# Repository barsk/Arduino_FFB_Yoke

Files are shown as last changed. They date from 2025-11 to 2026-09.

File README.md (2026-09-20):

# SimInvent FFB Yoke 
A Force Feedback Yoke based on 775 DC motors and an Arduino (SparkFun) Micro Pro microcontroller. 

This is a fork of [Gagagu Arduino FFB Yoke](https://github.com/gagagu/Arduino_FFB_Yoke). The goals of this fork was to lower total cost, add new features, achieve a smaller footprint, use cheaper and use more accurate AS5600 magnetic encoders and maximize pitch travel distance.

# Documentation
***All build guides and documentation for the 3D printed parts, electronics and software are in the [Wiki section!](https://github.com/barsk/Arduino_FFB_Yoke/wiki/Home)***

# Support
The [SimInvent Discord Server](https://discord.gg/cZUywYGyt6) is the main support and chat channel for this project. You are welcome to chime in and join the community there!<br>
**Bug reports**, please create an [Issue](https://github.com/barsk/Arduino_FFB_Yoke/issues) so we can track bugs and issues. 

---

> # Version 1.0 Release
> First public feature complete release with a **host of new features and performance**
>
> ## Firmware
> The firmware is now **highly optimized** compared to the previous version.
> It is now **100% compliant** with the standard Microsoft USB PID 1.0 specification with the following notable changes and bug fixes:
> * Force loop rate runs about  **2.5 times as fast** due to optimizations in every part of the firmware - 
> * Sine lookup table with interpolation replaces the computationally expensive sin() function in the force loop  - Contributing 45% of the speedup in the force loop
> * Effect direction now follows the DirectInput specification fully - Force directions was previously **inversed** in some situations
>* Multi-second FFB command lag removed when several effects were playing simultaneously with high framerate - 
> Due to inefficient USB protocol reads the input queue could build up and cause multi second lag
> * Effects no longer cancel or distort each other under load - The force calculator routine summed up effect forces 
> incorrectly causing an internal integer overflow
> * Coasting at idle - The motor output stage was driven even when idle, so the yoke was efffectively braked when zero force was applied. This has now been fixed, at 0 force, the output stage disbles leaving the yoke unpowered.
> * Handling non-linear motor response - The 775 motor driven straight from a PWM from 0-255 will yield a non-linear response. First at PWM=~25-40 the axis will start to move at all. Not handled this will create a huge deadband. We have previously handled this in the Setting tool with a "Motor Start Power" to define a starting point from which the effects should start, that settles the starting point, but the response *over* that setting will be non-linear with an initial bump unrealistically amplifying small effect forces. There are now settings in the firmware to configure the handling of this. See [Handling non-linear motor response](https://github.com/barsk/Arduino_FFB_Yoke/wiki/Firmware#handling-non-linear-motor-response) in the Wiki Firmware section.
>
> ## New pitch axis design
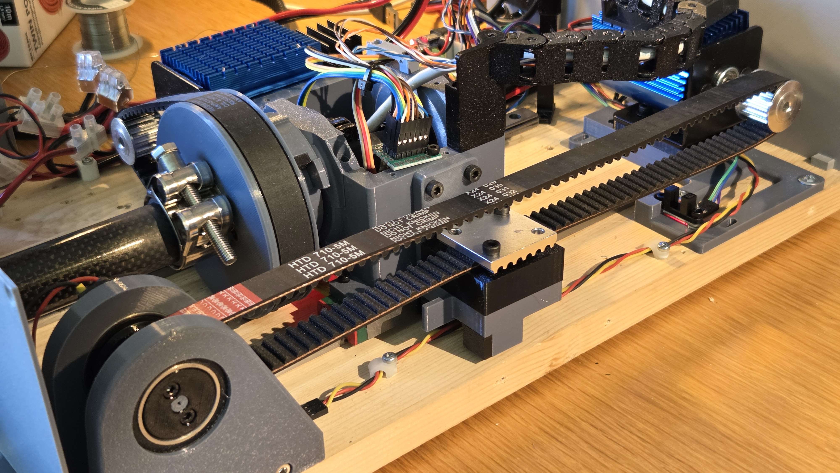
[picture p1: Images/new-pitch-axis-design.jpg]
new pitch design
> 
> The pitch axis previously featured a planetary gear on the motor. That gave the axis plenty of torque, but also introduced backlash 
> and friction. The backlash creates a lot of rattle on vibration effects and the friction makes the axis a bit numb on smaller forces.
> The new design removes the planetary gear and instead uses a 14T pulley with a 720 mm belt. This trades some of torque, but the pitch axis is still about 70% stronger than roll anyway. 
> The upside is that **pitch now feels nimble and direct**, you are more connected to the sim and aircraft and can feel it in you hands.  
> 
> If you built the former 30T + gears based version you need to get a new metal motor bracket (same as on roll), a 14t pulley and a 720 mm belt. You will also need to print a new idler pulley (also 14T), print a new frame belt clamp piece for the new raised belt position, and a new pitch motor mount for the new height.
>
> The previous design with planetary gears can still be used, see Wiki for details.
> ## FFBTestTool
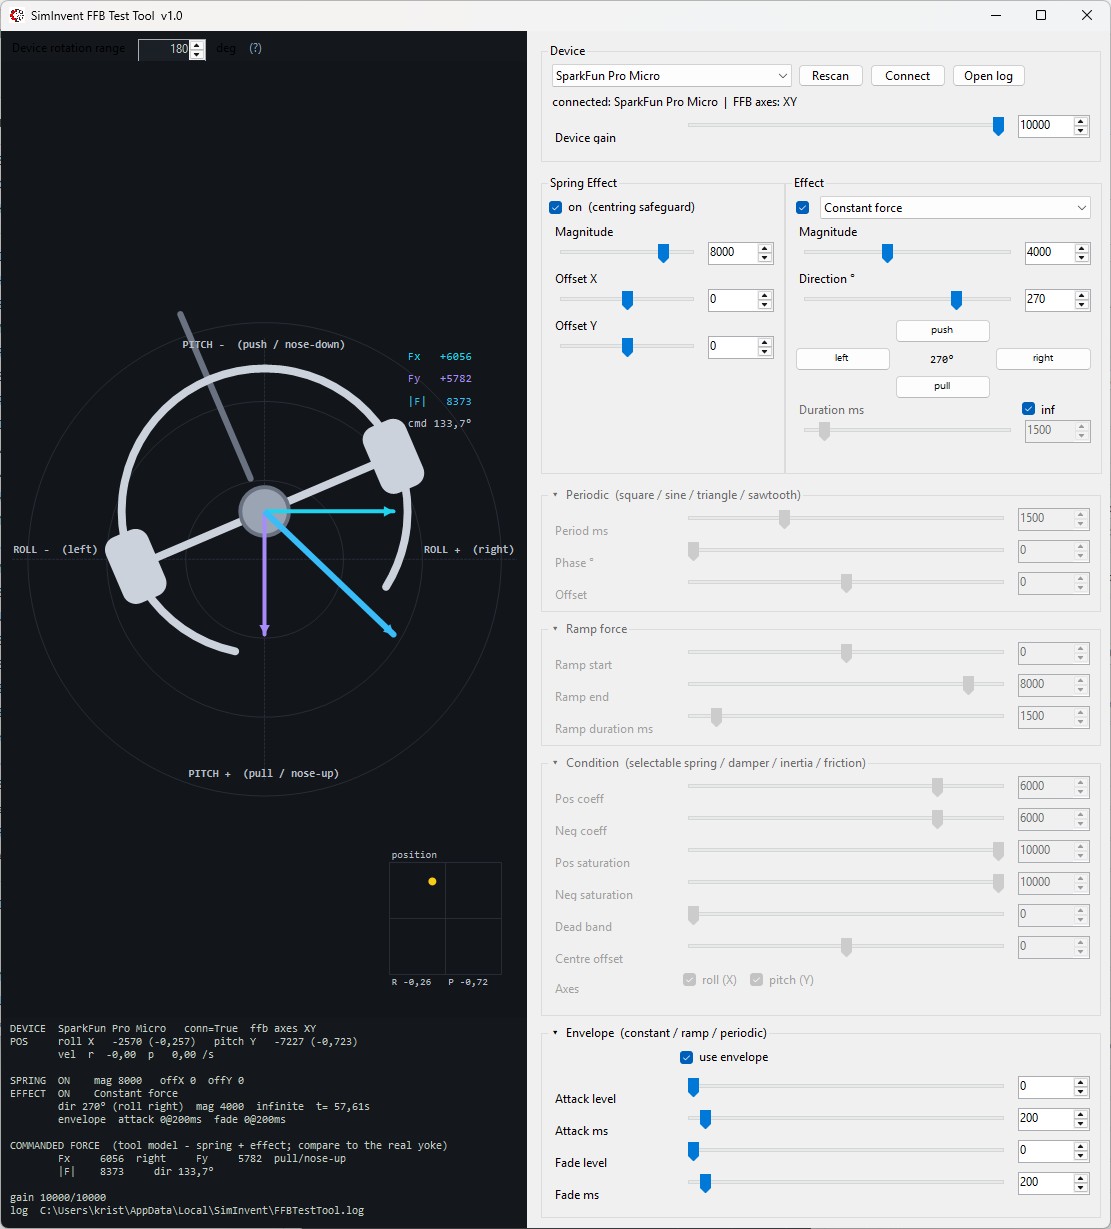
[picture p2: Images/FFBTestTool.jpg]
FFBTestTool

>There is now a new bundled **FFBTestTool.exe**, replacing the old ForceTest.exe that show you exactly what the 
> firmware sees from your built yoke, helping diagnosing magnetic encoders, travel, reversed motor wiring and 
> other faults, and confirming that every FFB effect is running and performing as expected with a graphical 
> view of the yoke and the forces applied to it.\
> Full details in https://github.com/barsk/FFBTestTool
> 
> ## Electronics
> The new PCBs (circuit boards) are now **fully tested!** Many thanks to **@PeteDDD** for his valuable contribution. All details are in the Wiki, Parts List and in the Electronics folder.

# Design and features compared to Gagagu Yoke
 
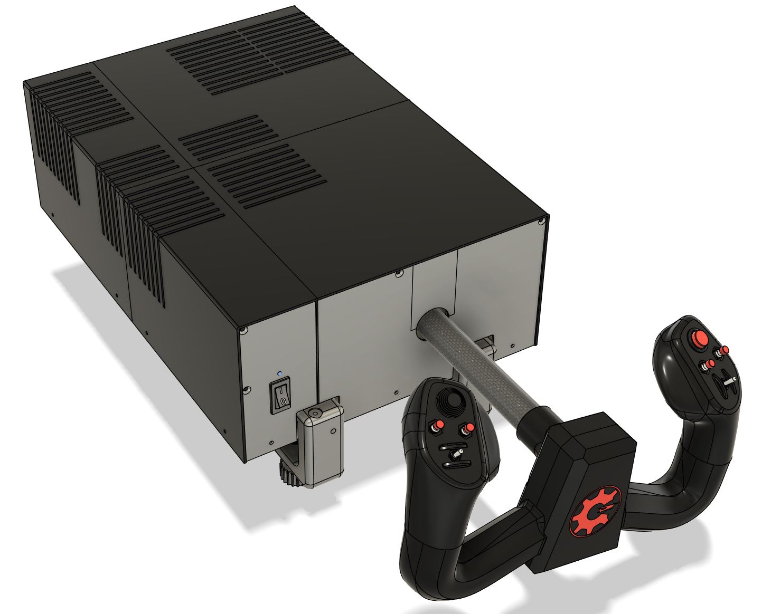
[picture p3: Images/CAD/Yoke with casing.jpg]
Yoke with casing
  
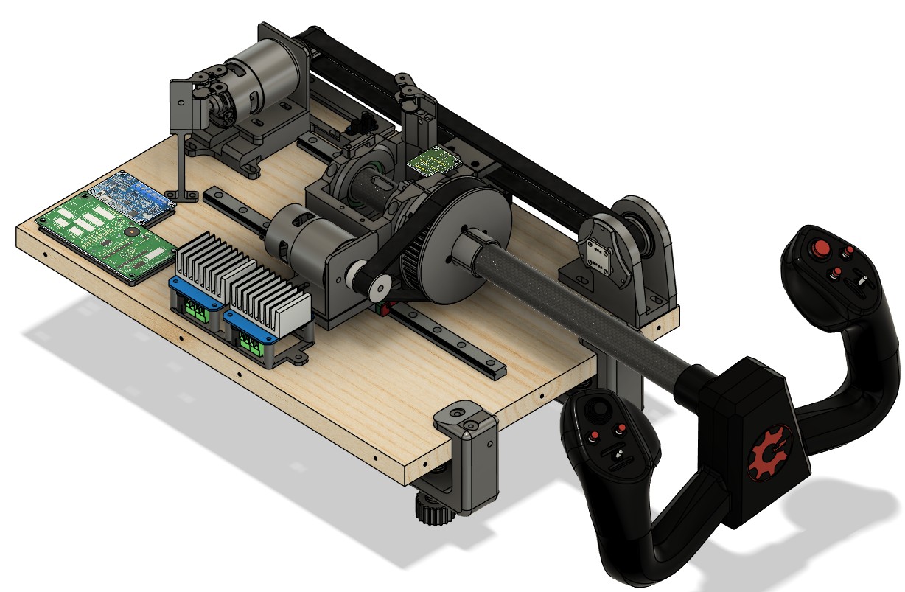
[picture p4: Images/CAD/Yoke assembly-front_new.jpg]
Yoke front

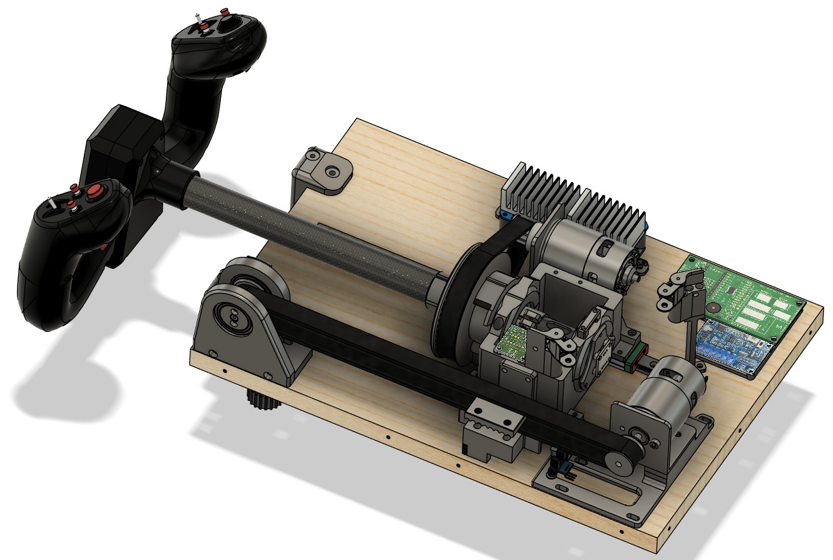
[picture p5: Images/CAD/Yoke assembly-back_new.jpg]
Yoke backside


* Completely new CAD design with focus on easy printing and assembly.
* New PCB design.
* Magnetic AS5600 encoders featuring 12 bit accuracy, saving cost, space and weight.
* Removed planetary gears in both roll and pitch axis which introduces backlash (slop), friction and considerable weight increasing mass and inertia. Roll axis with a 56T pulley, 12T motor drive. That gives a 4.7 gear ratio which is quite enough for roll forces and provides a more nimble, lively feel than the old design. Pitch axis now uses a 14T pulley. 
* Reduced footprint (400 x 275 x 100 mm).
* Pitch travel up to 165 mm with 720 mm belt on pitch (Y) axis. 
* Configurable pitch travel range in the settings tool.
* Default centering Spring force when non-FFB games are played.
* Yoke controller is remixed so that only 3 mm brass thread inserts is used. The mount bracket is updated for strength.
* Calibration method is completely revamped. It runs automatically on first start to find the endstops (IR sensors) at the extremes of the axis travel. It can also be manually started by a button at any time. 
* The calibration data is stored in EEPROM and recalled on subsequent reboot. 
* Cable chain link. To prevent breakage of the cabling a chain link is used in the design. This will give all cables from the yoke handle and frame sensors a controlled bend characteristic with a big radius preventing acute bending and breakage. 
* A 3D printed casing with plenty of cooling slots for ventilation is part of the design and fully integrated. The casing is split up into four parts plus the front and back panels which is split in two each, providing a fully printable design despite its large size. The parts are assembled with (printed) dowels and glued or screwed together.

### Electronics and PCB (circuit boards)
**@PeteDDD** has graciously contributed new custom PCB designs. 
Gagagu version PCBs can still be used, with some modifications (see Wiki).
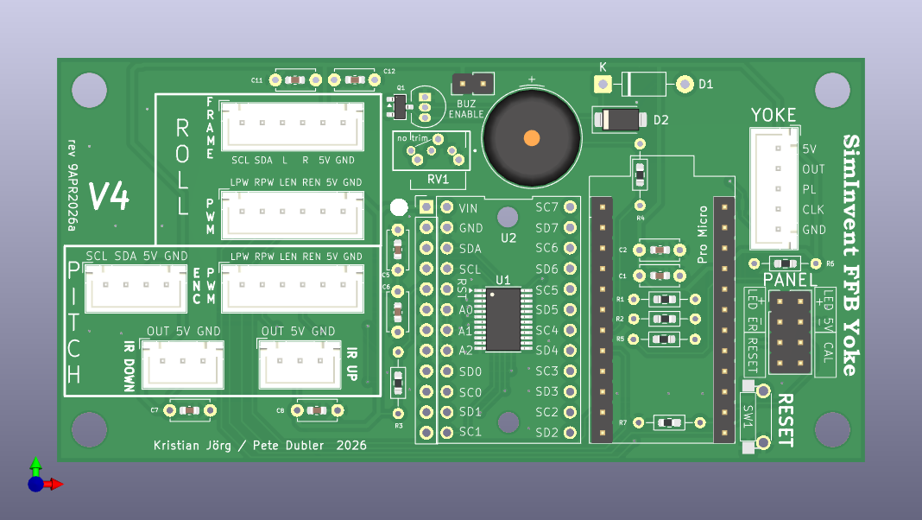
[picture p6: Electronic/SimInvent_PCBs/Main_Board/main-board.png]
New PCB


### Settings tool
A settings tool written in Python and Qt6. The tool features a sleek experience and features a robust and fast serial protocol.

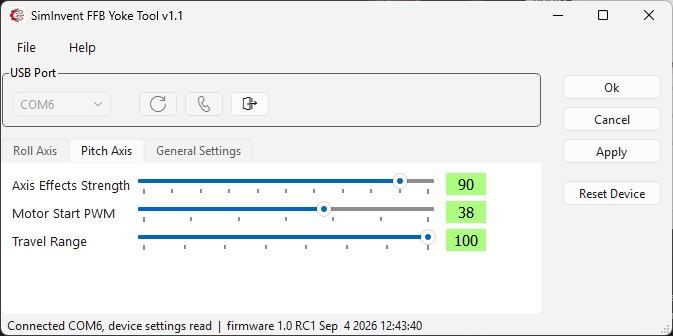
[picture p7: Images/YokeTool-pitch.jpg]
Settings tool


### 3D printed parts
No 3D printed parts are the same from the Gagagu/jwryan4 project. Every part has been redesigned from the ground up with focus on easy printing, strength, functionality and minimal footprint. The IR-based end-stop sensors are now integrated into the actual design in a way that need no careful positioning as before.

### Firmware
The firmware code is *heavily modified and enhanced* with new features and updated for the new AS5600 encoders and a TCA9548 I2C mux. 
With heavy optimizations it was possible to squeeze all the performance and features into the Atmega32u4 28 KB Flash ROM of the Arduino Pro Micro with just a few bytes to spare!

### FFB Effects
The actual FFB effects are based on the [FINO](https://github.com/jmriego/Fino) project but have undergone bug fixes and heavy optimization to increase speed, lower latency and lower FLASH size.

#### Games with native FFB
For games that themselves handles standard FFB effects such as IL2 and DCS the yoke will work when connected, as it fully handles the standard DirectInput PID protocol (currently untested, but *should* work!).

 ####  Microsoft Flight Simulator, Xplane and others without FFB effects
 Since MSFS and others don't have any FFB effects implemented we have to rely on external software to interpret telemetry data from the sim and create effects accordingly. 

 * [**DirectLink** with **TelemFFB** from VPForce](https://directlink.flyfrisby.com/) A new contender, **free** download, which creates the link between TelemFFB, which formerly only could only interact with its own Rhino devices, can now interact with standard DirectInput FFB devices. Currently in Beta, but works fine with SimInvent FFB Yoke! 
 
* [FFB-Bridge](https://ffb-bridge.com/) - A great **free** force-feedback application for flight simulators on Windows, Linux, and macOS, developed and published by Rohsam Inc.

 * [XPForce](https://www.fsmissioneditor.com/product/xpforce/) - Commercial product (subscription), works for MSFS, Xplane, Flight Sim world and Prepar3D. 
 
I am not affiliated with these softwares, nor is this in any way a comprehensive list, there may be other options.

### Assembly
For easy assembly there is a number of options: 

* A printable "bracket" that can be used to position the right rail correctly. The other parts will then be easy to postition relatively that rail or the edge of the board. 
* Drill template (drawing) for the bottom board that can be printed in 1:1 scale and layed out on the board to easily position the components. 
* The STEP file of the board with all (threaded) screw holes in the correct spots can be used to machine the board on a CNC router. 

These method are described in the [Wiki Build-Guide](https://github.com/barsk/Arduino_FFB_Yoke/wiki/Build-Guide).

## Limitations
The design has some drawbacks that need to be taken in consideration.

* DC motors are not as efficent as brushless BLDC motors. They overheat sooner if pushed hard.  
* There is a slight cogging sensation in the rotation of these motors than with BLDC motors (that can use anti-cogging algorithms in the motor drivers to counter the effect)
* The microprocessor is limited to 16 MHz which leaves little headroom if many effects are playing simultaneously. There heas been a great effort put into finding optimizations on every possible front to squeeze the absolute most of this device. With about 10-15 effects playing at the same time we can do periodics (sine, triangle etc) up to about 90-100 Hz, which should cover most if not all real world scenarios. And if we reach the ceiling the periodic will drop a little in frequency, that is basically all.

The motors (775 DC) and BTS7960 43A drivers are easy to find and come at a very low cost. Better microprocessors, BLDC motors and drivers are at the next level cost wise, and what we achieve with these components is pretty impressive!
Just keep in mind the possible overheating problems and do not use strong forces sustained for a prolonged time as this can overheat the motors. Heatsinks on the motors and a fan controller that kicks in at about 40 centigrades is mandatory. When you hear the fan power up, you know you are pushing it. That said, when flying normally with the aircraft properly trimmed this practically never occurs. Heatsinks, fan controllers and fans are all in the Parts List (see [Wiki section](https://github.com/barsk/Arduino_FFB_Yoke/wiki/Part-List)).

## Credits
*I wish to thank **@PeteDDD** for invaluable help with professional level proof reading and for the new quality PCBs.*

### Some of the Github projects this is based on.
* [FINO](https://github.com/jmriego/Fino)
* [Rob Tillaart, AS5600](https://github.com/RobTillaart/Arduino/tree/master/libraries/AS5600)
* [Rob Tillaart, TCA9548](https://github.com/RobTillaart/Arduino/tree/master/libraries/TCA9548)

### Thingiverse
* [Cadet Yoke v2.0](https://www.thingiverse.com/thing:4884092)
* [Ender 3 Cable Chain](https://www.thingiverse.com/thing:2920060)

## Using this project commercially is strictly disallowed
If you want to use this project commercially please contact me.

# Disclaimer!
> [!Important]
> Use at your own risk. I am not responsible for any damage or injury to man or machine. Be careful when handling electric installations, electronics and mechanics. If handling electrical installation (230V) by yourself is not legal in your country or you feel unsure of your competence, take proffessional help! <br>
The motors are quite strong and can cause serious injuries if not handled with great caution. The yoke handle can move very quickly when power is applied. Be aware of moving parts, belts and pulleys.

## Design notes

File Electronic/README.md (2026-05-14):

Contents of this folder:
* Fritzing - source files for the wiring schematics
* SimInvent_PCBs - The new PCBs by @PeteDD
* Legacy - The older Gagagu v2.0 PCBs. These are compatible, but please see the Wiki for details covering the special fixes made.
* PCB_pictures - Rendered PCB images. Note, additional images can also be viewed in the [Wiki Electronics section](https://github.com/barsk/Arduino_FFB_Yoke/wiki/Electronics)
* Wiring_diagram -  Diagram of the overall wiring

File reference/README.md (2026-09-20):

# Tools and documents

| File | What it is |
|---|---|
| `pwm-torque-measurement.csv` | Round 1 of the PWM-vs-torque bench sweep, both axes: the magnitude grid with its PWM and duty worked out, the required firmware and tool setup, and the geometry constants for converting a scale reading to motor torque. Readings above magnitude ~6000 are limited by its 10 A supply, which sagged to about 12 V at full duty. |
| `pwm-torque-measurement-round2.csv` | Round 2: pitch only, push direction, on the 20 A supply and after the pitch belt was slackened. Round 1's pitch readings sit alongside each row. Peak 4,42 kg from cold at full magnitude - 43,4 N at the handle. |
| `pwm-torque-measurement-round3-roll.csv` | Round 3: the roll axis from 4000 to 10000 on the 20 A supply, re-measuring the range where round 1's supply had folded back to ~12 V. Blank sheet, ready to fill. |
| `pid1_01.pdf` | USB Device Class Definition for Physical Interface Devices (PID) 1.0, the official Microsoft Force Feedback specification the firmware's FFB layer implements. |

Both sheets are semicolon-separated with a decimal comma.

`FFBTestTool.exe` used to live here; it is now in
[`../tool/other/`](../tool/other/) with its licence and source pointer.

---

## Reading an effect's direction

Getting this right takes two documents, and neither is enough on its own.

- **[`pid1_01.pdf`](pid1_01.pdf) - USB PID 1.0** gives the **encoding**. An effect's
  direction arrives in the Set Effect report as one byte per axis, spanning 0-360 degrees
  over 0-255, so one count is about 1.41 degrees. The firmware holds it as
  `effect.direction[0]`.
- **[Microsoft - *Effect Direction*](<https://learn.microsoft.com/en-us/previous-versions/windows/desktop/ee417536(v=vs.85)>)**
  gives the **meaning**: an effect's direction is *the direction the force comes from*, so
  the force applied to the device is the opposite of the angle. It also fixes the frame -
  0 degrees points away from the user, and the angle increases clockwise.

The PID spec tells you where the number is and how it is scaled. The Microsoft page tells
you which way it points. With only the first, the natural reading is that the angle is the
way the force pushes, and that is exactly 180 degrees wrong. This project made that
mistake, changed working code to "fix" it, and had to revert; a spec-compliant wheel is
what finally settled it.

### The compass

Effect direction: a compass with 0 degrees at the top increasing clockwise, and an example showing direction 90 degrees pushing the device to the left

Angles are laid out like a compass bearing: **0 degrees at the top, increasing clockwise** -
0 north, 90 east, 180 south, 270 west. North is away from the user.

### What each direction does

| Direction | Force comes from | Device is pushed | Yoke / stick | Wheel |
|---|---|---|---|---|
| **0&deg;** north | ahead of you | backwards, toward you | pulls back - nose-up | no component on its axis - see below |
| **90&deg;** east | your right | to the left | rolls left - left wing down | turns counter-clockwise - steers left |
| **180&deg;** south | behind you | forwards, away from you | pushes forward - nose-down | no component on its axis - see below |
| **270&deg;** west | your left | to the right | rolls right - right wing down | turns clockwise - steers right |

Angles in between divide between the axes like any vector: 45 degrees comes from the
north-east, so it pulls back *and* rolls left, each at about 71 % of the magnitude.

### Single-axis devices are not covered by any of this

A device with one force axis - a wheel - can only feel the component along that axis. At 90
and 270 degrees that is the whole force. At 0 and 180 it is **zero**, and that is where the
convention runs out: a direction vector of zero has no direction, so what the device does
next is not defined by the specification at all. It is up to the driver and the firmware,
and it differs between devices.

Measured here on a Logitech RS50, 2026-09-12: **0 and 180 produced full force, identical to
90.** FFBTestTool's log confirms it sent `dir=[0]` for both and that DirectInput accepted the
call without an error, so the substitution happens somewhere on the Logitech side. Whether
that is the driver or the wheel's firmware is not visible from the DirectInput API; telling
them apart would need a capture of the HID PID Set Effect report.

Do not generalise from that. Another wheel may go quiet, or hold its previous direction, or
refuse the call. The only safe assumption is that 0 and 180 are undefined on a one-axis
device, and that if you need to know, you test that device.

Two further traps on single-axis devices:

- **Polar angles need two axes to begin with.** A genuinely single-axis effect takes a
  Cartesian +/-1, not an angle.
- **DirectInput normalises the direction vector** - only its direction matters, not its
  length. On one axis that collapses to a sign, so 45 degrees cannot be expressed as "71 %
  of full" through the direction. An application that wants a proportional force there has
  to scale the effect's *magnitude* itself.

Two axes, as on the yoke, has none of this ambiguity: the X component at 0 and 180 degrees
is genuinely 0, it is sent as 0, and the axis stays still.

### In the firmware

For polar angle `t`, the "comes from" vector is `(sin t, -cos t)`, and the force applied to
the axes is its opposite:

```
Fx = -sin t     negative = left
Fy = +cos t     positive = toward you, nose-up
```

That is what `getAngleRatio()` in [`../src/src/Joystick.cpp`](../src/src/Joystick.cpp)
builds, and the comment above it records the convention so the same mistake cannot be made
twice. FFBTestTool sends the DirectInput angle unchanged, so its 90 degree button pushes
the device left - matching TelemFFB and other DirectInput tools.

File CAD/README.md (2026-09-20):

# CAD files

This directory contains mesh files (STL) for all parts. Some critical parts are also offered in Fusion 360 format (.f3d) and STEP, to ease in remixing and tinkering. The Yoke Controller also has one 3MF file for the Console Front (Compartment lid) to make it possible to print the logo in color. 

Detailed guides for printing are found in the 3D Print pages of the Wiki.

> [!Note] 
> The AS5600 encoder bracket needs to be printed twice, one for each axis. There are two files for this STL, roll and pitch, as a reminder. They are identical though.

## Old design version parts
The old subdirectory contains the parts from the older design with a the old PCB boards and the 30T pulley

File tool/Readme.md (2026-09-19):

# tool/

Everything that runs on the PC rather than on the yoke, split by who it is for.

| Folder | For | Contents |
|---|---|---|
| [`settings/`](settings_tool/) | **users** | The yoke SettingsTool - Used for configuring and fine-tuning the yoke. |
| [`other/`](other/) | **builders & users** | Diagnostic tools. Currently SimInvent's **`FFBTestTool.exe`**, which diagnoses position, travel, endstop and motor wiring errors. It tests all FFB effects directly over DirectInput for diagnosing any wrong behaviour. |
| [`internal/`](internal/) | **firmware developers** | Development helpers for the firmware itself. Currently `gen_joydesc.py`, which regenerates the frozen PROGMEM HID report descriptor in `src/src/Joystick.cpp`. Nothing here is needed to use or configure a yoke. |

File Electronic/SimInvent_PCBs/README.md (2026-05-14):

This folder contain the KiCad project files and Gerber files needed for manufacturing of the SimInvent PCBs.

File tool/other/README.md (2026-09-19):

# Other tools

Tools that are useful when building, wiring or diagnosing the yoke, but are not part
of the firmware and not part of the settings tool.

| File | What it is |
|---|---|
| `FFBTestTool.exe` | SimInvent's test tool for FFB effects. Sends individual DirectInput effects to the yoke, one at a time, with a live force preview. The tool for verifying the physical build and wiring, and for seeing how each effect behaves before putting a sim in front of it. |

## Source for `FFBTestTool.exe`

`FFBTestTool.exe` is free software under the **GNU General Public License v3 or
later** - the same licence as this firmware. The complete corresponding source is at:

**https://github.com/barsk/FFBTestTool**

The binary records the commit it was built from in its version resource, so the
matching source is always identifiable:

```bat
powershell -c "(Get-Item FFBTestTool.exe).VersionInfo.ProductVersion"
```

Rebuild it from that repository if you would rather not trust a binary someone else
compiled, or if the one here is out of date.

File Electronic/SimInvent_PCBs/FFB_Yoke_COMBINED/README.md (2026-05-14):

This folder contains KiCAD and GERBERS for manufacturing all PCBs in a combined fashion. This will save some cost for individual boards, but will require you to cut the boards by yourself. Perhaps with the use of a Dremel with a cutting disc or similar tool.

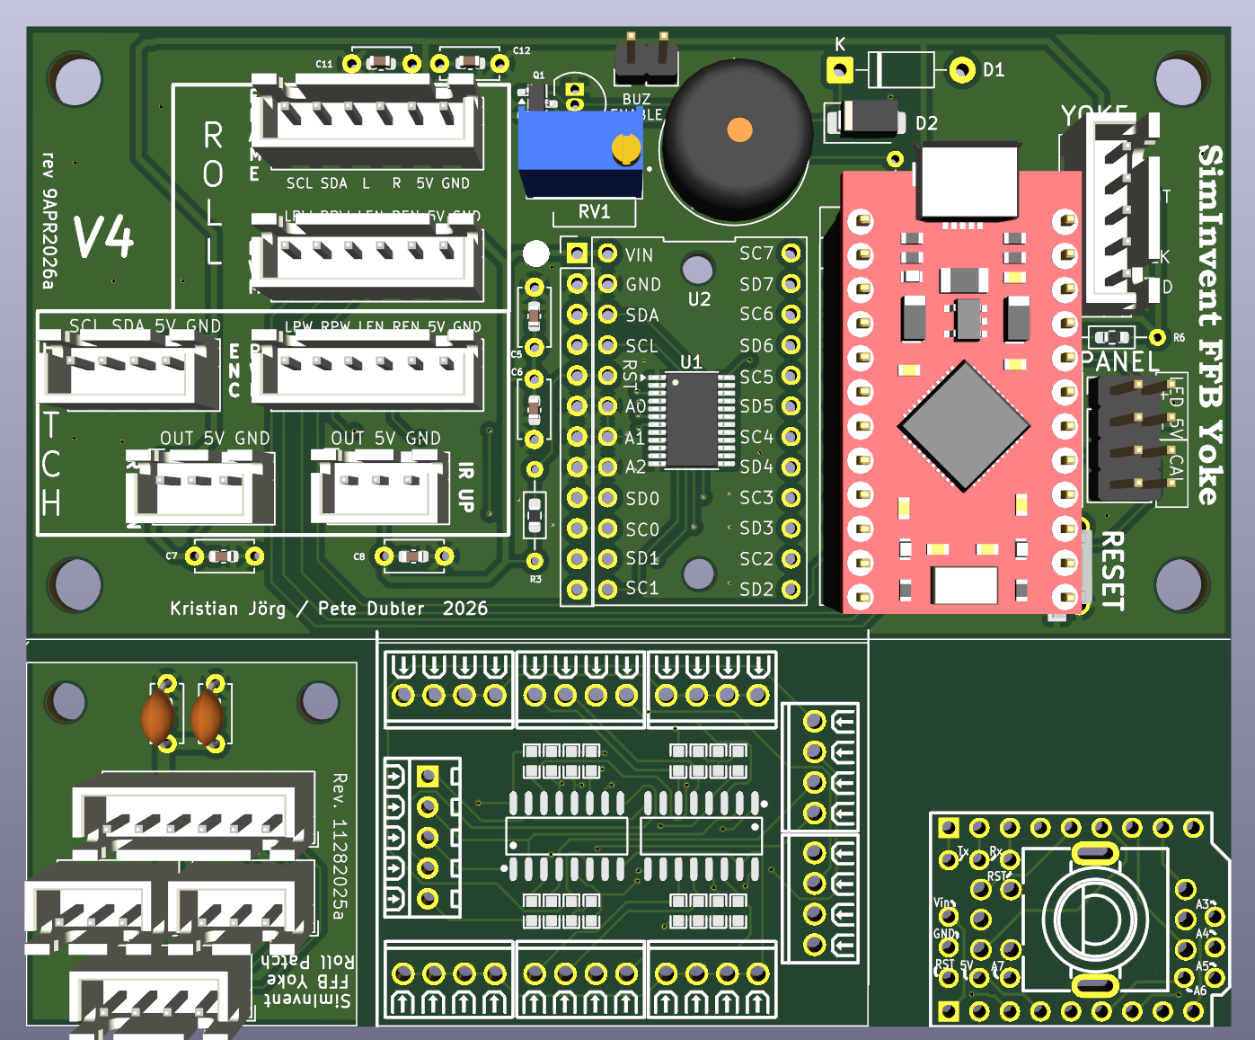
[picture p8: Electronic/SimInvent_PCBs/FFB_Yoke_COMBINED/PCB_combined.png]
PCBs combined


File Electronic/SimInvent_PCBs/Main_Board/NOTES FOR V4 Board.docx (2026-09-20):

NOTES FOR V4 Board

1. Buzzer volume trimmer option: If you don't want to have the ability to adjust the volume

of the buzzer, you can elect not to install the trimmer and instead install a wire jumper where "no trim" is marked on the board. Trimmer pads can accept long or square format trimmers.

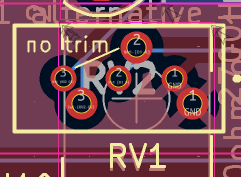
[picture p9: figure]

2. Buzzer enable can be a 2-pin 2.54mm pin header with a jumper cap OR if you do not want the ability to disconnect the buzzer, can just be a jumper wire.
3. Buzzer pads can accept buzzer with 6mm or 5mm connector spacing.

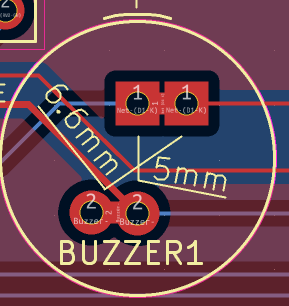
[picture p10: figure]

4. Do not populate D1/D2. This diode is not needed can interfere with Error LED and Buzzer.
5. On-board reset button is optional but convenient to have.
6. TCA9548A (I2C mux) cards are available with two different pin strip spacings. That is why there is a double row of pin pads on one side of the footprint. Use the set that fit your board if you are using the module instead of the SMD chip. If using the module version, it is recommended, but not mandatory, that you use a pin socket strip on the board instead of soldering the module directly to the board.
7. All resistors, capacitors, diodes, and the transistor can be either SMD or THT components. Similarly, the TCA9548A may be a module or just the SMD chip. Use either the SMD component or the THT component for each part (not both). You can mix SMD and THT components on the board if you wish.
8. It is recommended, but not mandatory, that you solder a pin socket strip to the board to plug in the Pro Micro rather than solder the Pro Micro directly to the board.

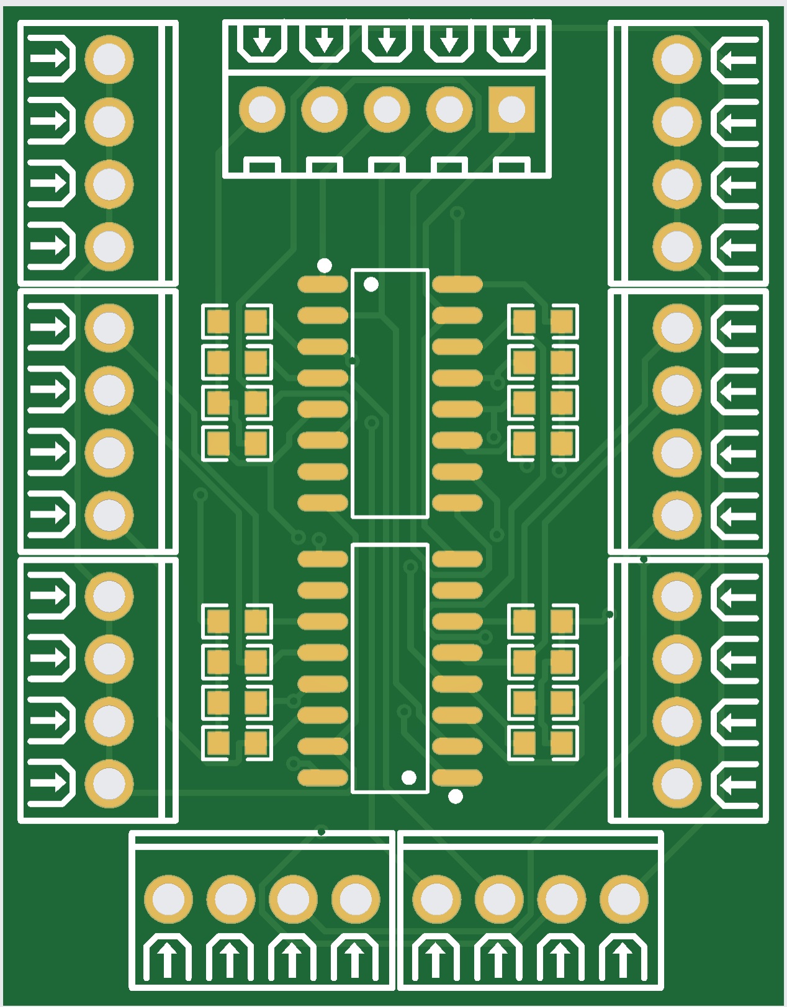
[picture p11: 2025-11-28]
Electronic/SimInvent_PCBs/Yoke_Board/Yoke_Board.jpg

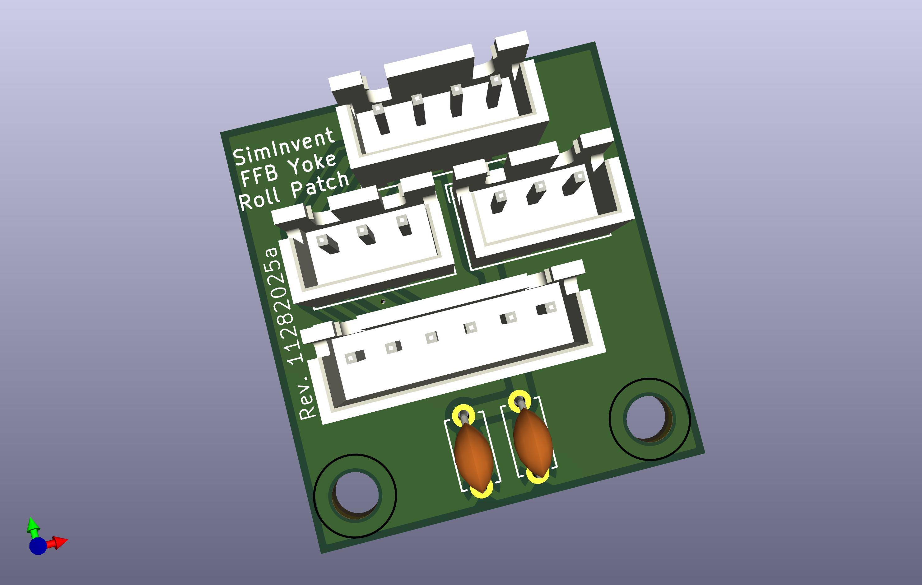
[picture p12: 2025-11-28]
Electronic/SimInvent_PCBs/Pitch_Patch_Panel/SimInvent-Pitch-Patch-Panel.jpg

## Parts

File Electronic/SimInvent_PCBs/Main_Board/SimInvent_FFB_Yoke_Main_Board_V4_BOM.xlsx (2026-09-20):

Designator | Comment | 'Footprint' | LCSC | 'Qty'
BUZZER1 | 2700Hz passive Fuet FS9012-03 | Buzzer_Beeper:Buzzer6mm | C96256 | 1
C1,C5,C7,C8,C11 | 0.1uF | MyFootprints:DUAL_CAP_2.5mm_0603 | C14663 | 5
C2,C6,C12 | 10uF | MyFootprints:DUAL_CAP_2.5mm_0603 | C19702 | 3
J1 | Frame Cable | Connector_JST:JST_XH_B6B-XH-A_1x06_P2.50mm_Vertical | C144397 | 1
J2 | Roll Motor | Connector_JST:JST_XH_B6B-XH-A_1x06_P2.50mm_Vertical | C144397 | 1
J3 | Pitch Motor | Connector_JST:JST_XH_B6B-XH-A_1x06_P2.50mm_Vertical | C144397 | 1
J4 | Pitch Encoder | Connector_JST:JST_XH_B4B-XH-A_1x04_P2.50mm_Vertical | C144395 | 1
J5 | IR Pitch Down | Connector_JST:JST_XH_B3B-XH-A_1x03_P2.50mm_Vertical | C144394 | 1
J6 | IR Pitch Up | Connector_JST:JST_XH_B3B-XH-A_1x03_P2.50mm_Vertical | C144394 | 1
J7 | Jumper - Buzzer Active | Connector_PinHeader_2.54mm:PinHeader_1x02_P2.54mm_Vertical | C492401 | 1
J8 | Yoke | Connector_JST:JST_XH_B5B-XH-A_1x05_P2.50mm_Vertical | C161872 | 1
J9 | Conn_02x04_Counter_Clockwise | Connector_PinHeader_2.54mm:PinHeader_2x04_P2.54mm_Vertical | C492421 | 1
Q1 | MMT4401 alternative | Package_TO_SOT_SMD:SOT-23 | C181123 | 1
R1,R2,R3,R7 | 10K0 0603 | MyFootprints:DUAL_RESISTOR_7.62mm_0605 | C25804 | 4
R4 | 2K0 0603 | MyFootprints:DUAL_RESISTOR_7.62mm_0605 | C22975 | 1
R5,R6 | 220ohm 0603 | MyFootprints2:DUAL_RESISTOR_7.62mm_0605 | C22962 | 2
RV1 | 3296W 500ohm | SamacSys_Parts:3296W1503LF | C48641775 | 1
SW1 | PTS636SM43LFS 6X3.5MM | MyFootprints:DUAL_TACTILE_SWITCH | C2689636 | 1
U1 | TCA9548APWR | Package_SO:TSSOP-24_4.4x7.8mm_P0.65mm | C130026 | 1
D2 |  | DO NOT POPULATE |  | 1
J112,J113,J114 | 1x12P 2.54mm female pin socket THT | KH-2.54FH-1X12P-H8.5 | C2905419 | 3
J111 | 2x12P 2.54mm female pin socket THT | DS1023-2*12SF11 | C92265 | 1

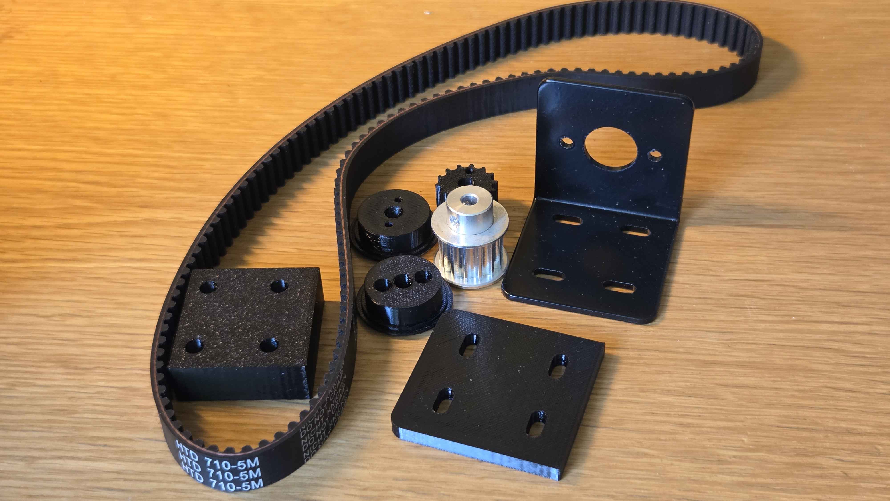
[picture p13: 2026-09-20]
Images/new-pitch-axis-parts.jpg

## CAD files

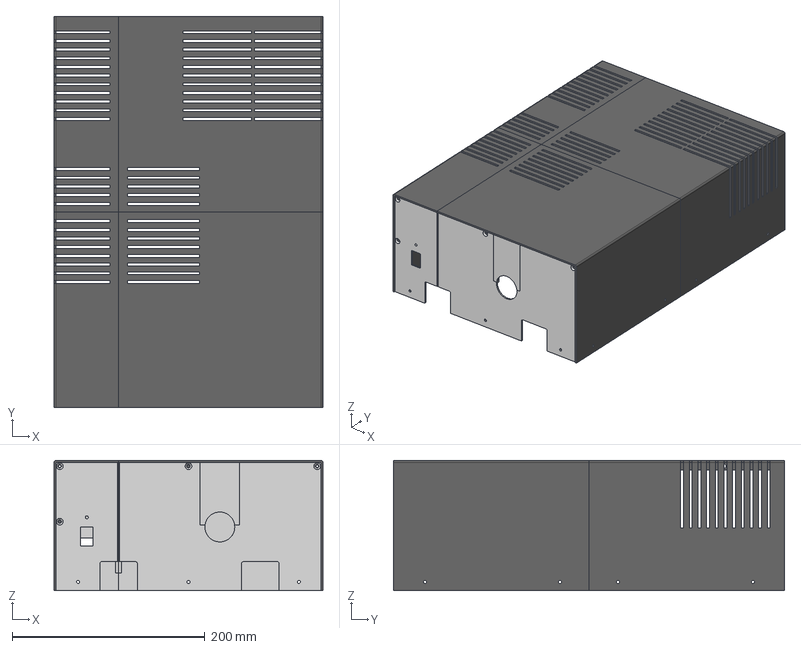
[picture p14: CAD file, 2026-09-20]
CAD/Case assembly 18mm.step
279.0 x 406.0 x 135.0 mm

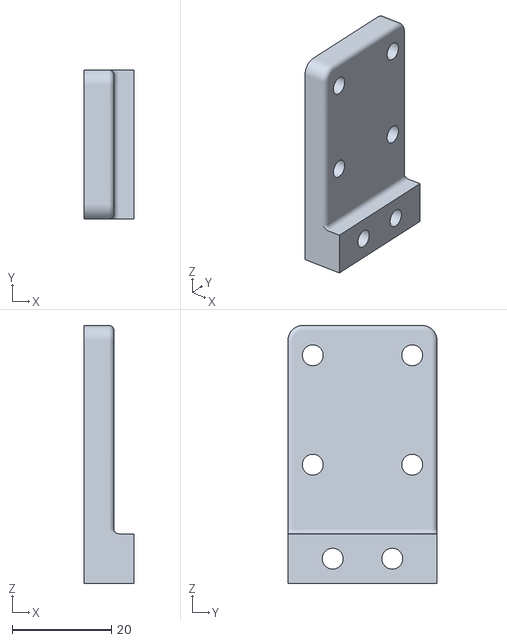
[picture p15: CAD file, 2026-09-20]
CAD/Frame - Belt clamp wall.stl
10.0 x 30.0 x 51.9

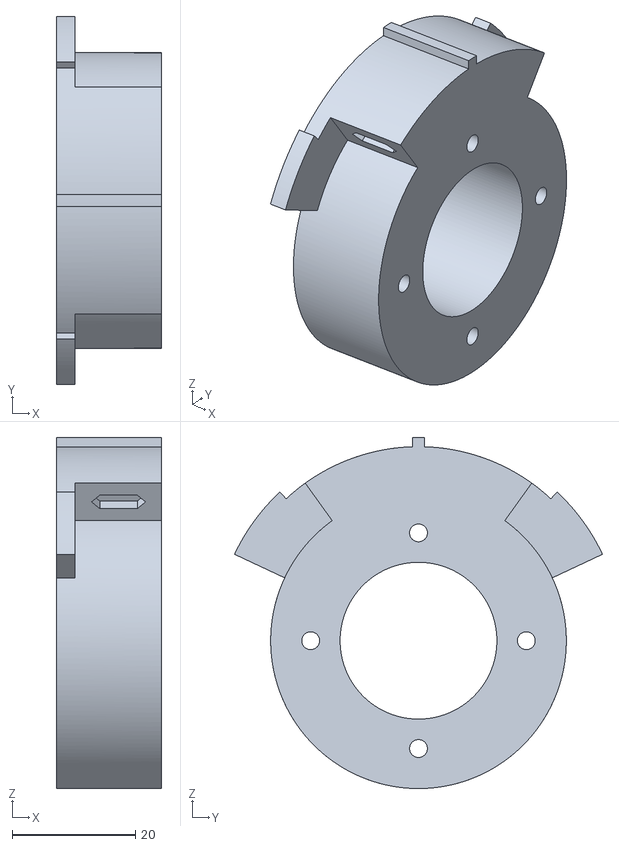
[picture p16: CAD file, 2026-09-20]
CAD/56T pulley - Yoke Column End Stop.stl
17.0 x 59.7 x 57.0

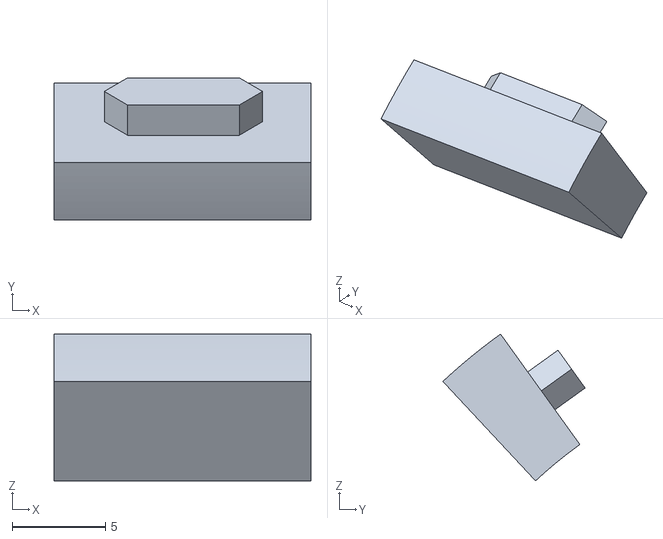
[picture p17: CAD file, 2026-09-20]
CAD/56T pulley - Bumper pulley R.stl
13.8 x 7.64 x 7.88

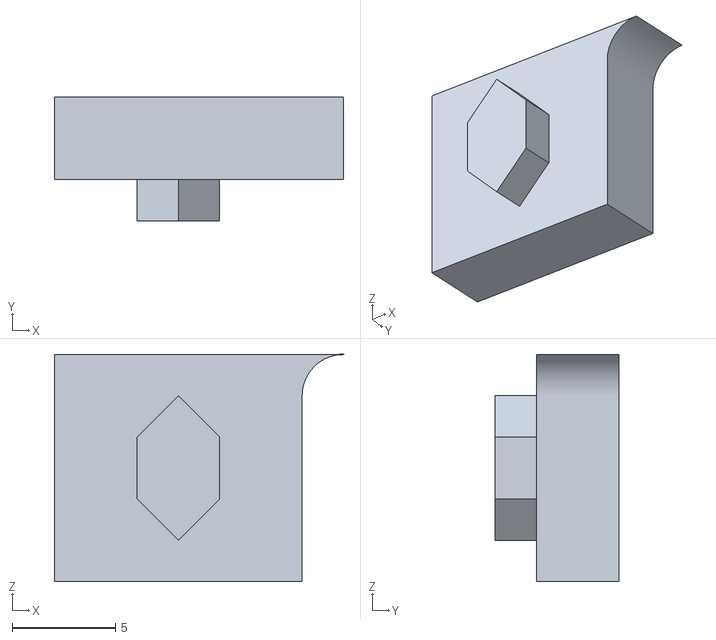
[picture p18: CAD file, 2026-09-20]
CAD/Frame - Bumper frame R (back).stl
14.0 x 6.00 x 11.0

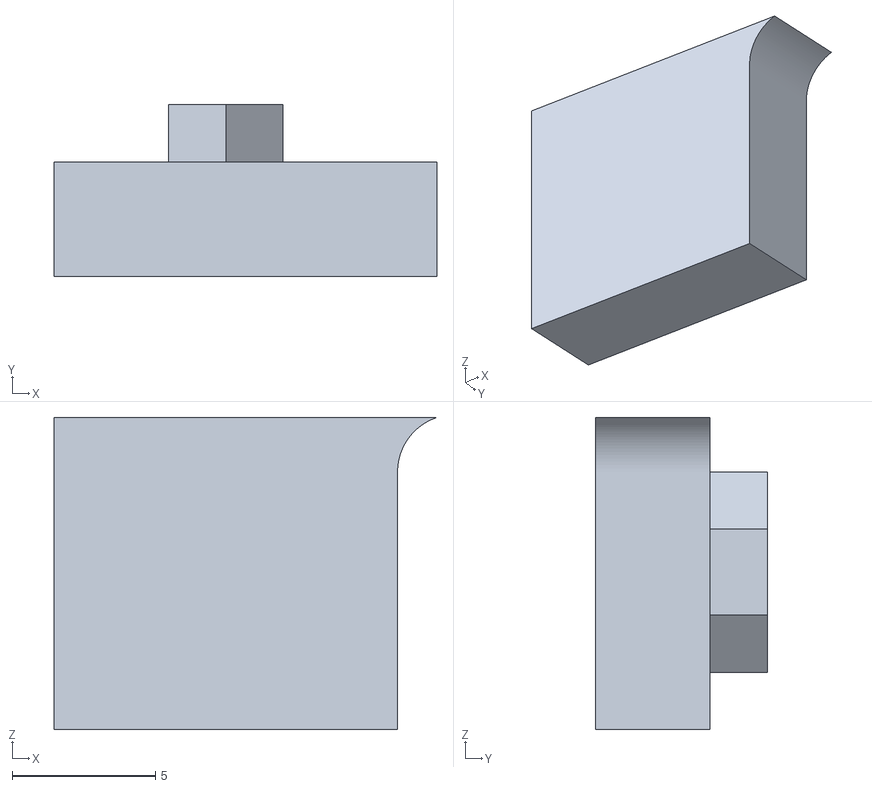
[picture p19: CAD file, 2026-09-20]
CAD/Frame - Bumper frame L.stl
13.4 x 6.00 x 10.9

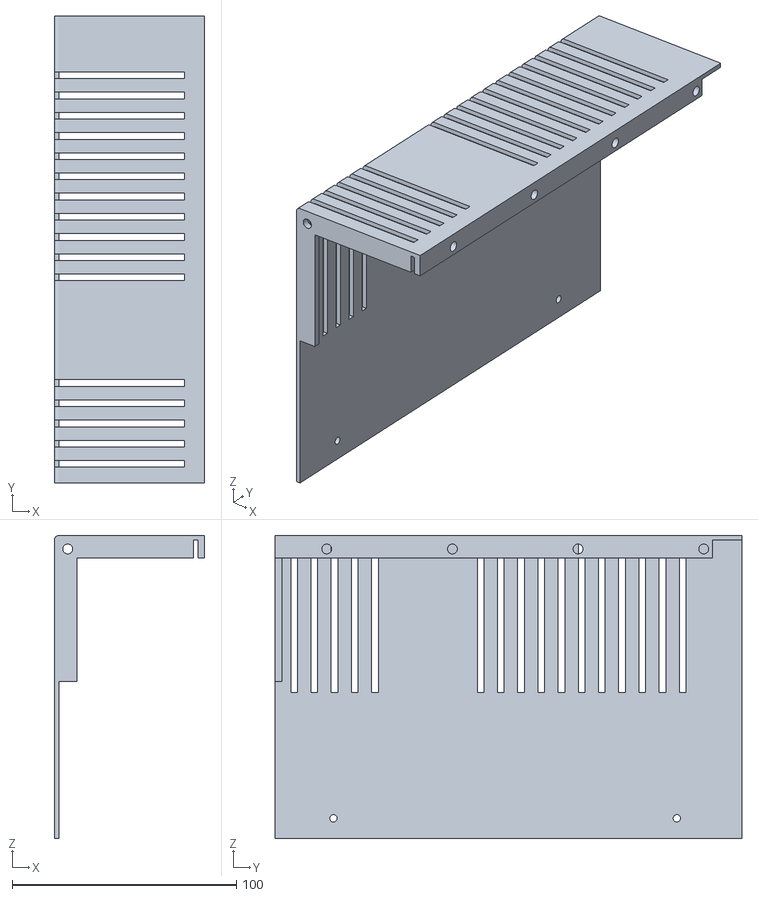
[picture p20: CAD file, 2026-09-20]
CAD/Case - Left cover rear.stl
67.0 x 208.0 x 135.0

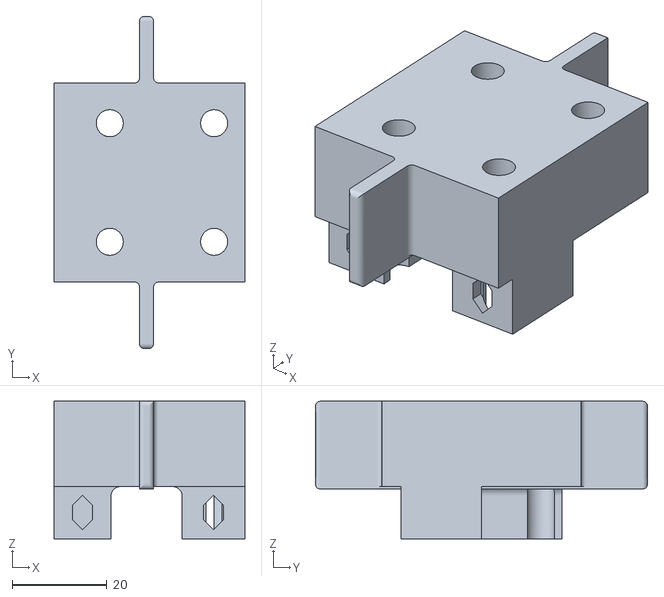
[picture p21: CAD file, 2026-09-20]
CAD/Frame - Belt clamp hor_14T.stl
40.2 x 70.0 x 29.0

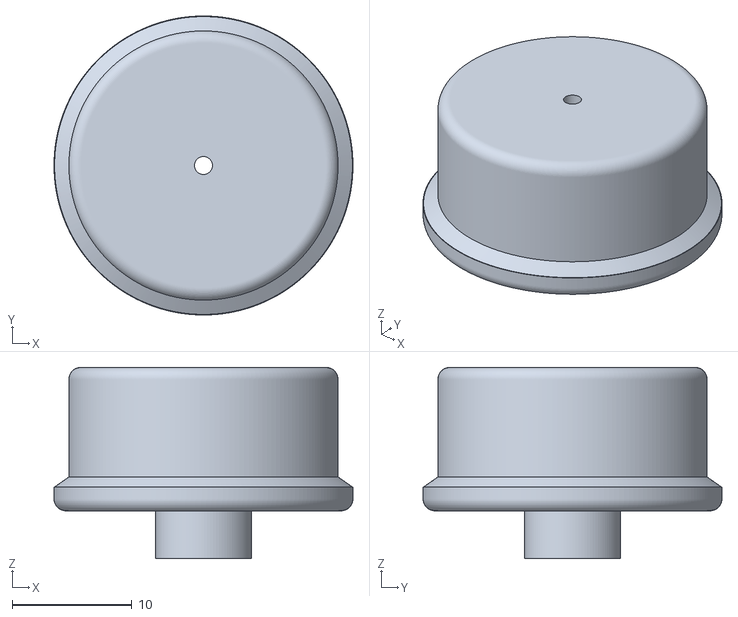
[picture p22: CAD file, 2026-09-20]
CAD/Magnet mount - Roll.stl
25.0 x 25.0 x 16.0

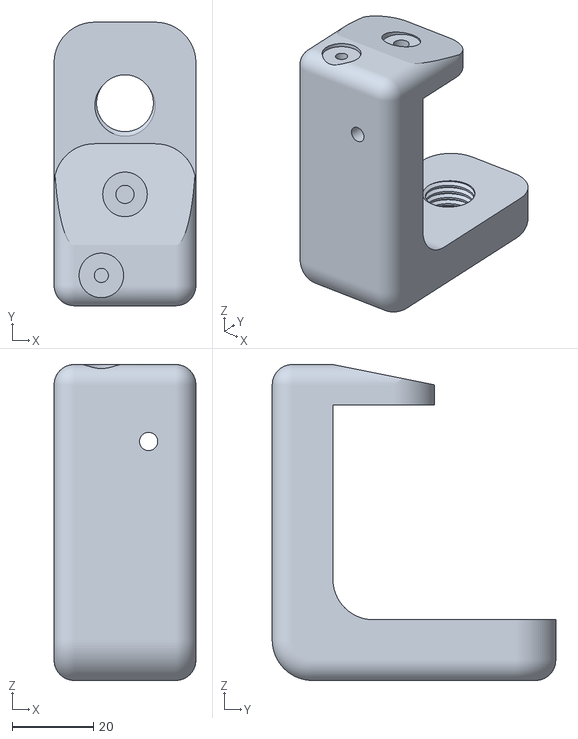
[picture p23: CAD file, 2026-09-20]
CAD/Desk clamp.stl
35.0 x 70.0 x 78.0

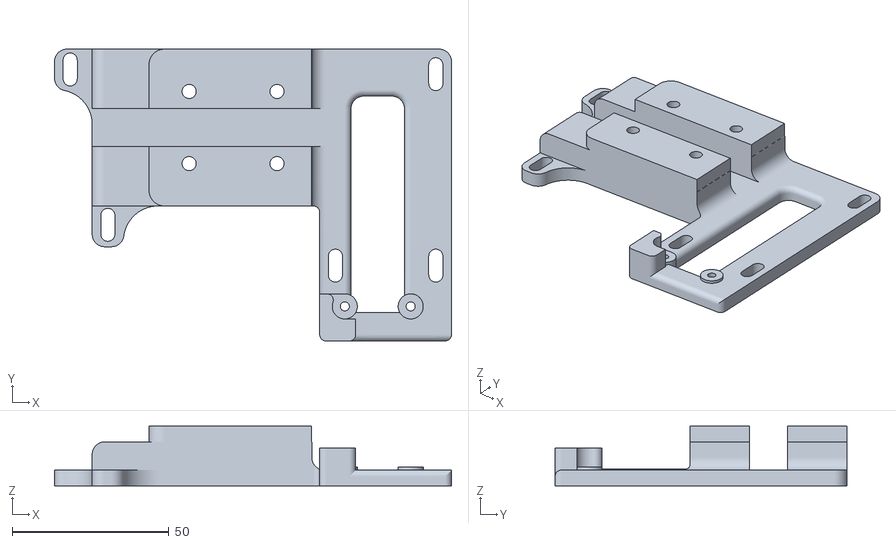
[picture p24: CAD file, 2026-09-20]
CAD/Pitch Motor Mount_14T.stl
126.5 x 93.0 x 19.0

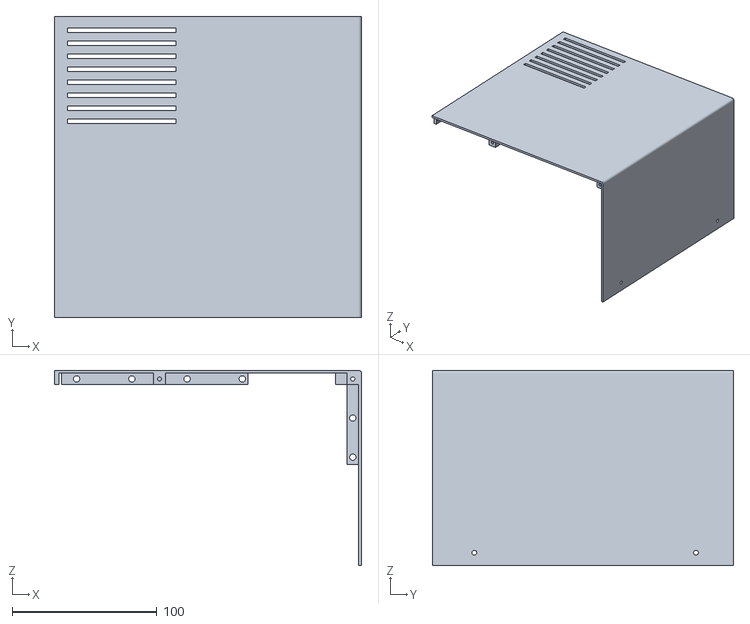
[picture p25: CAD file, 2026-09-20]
CAD/Case - Left cover front.stl
212.0 x 208.0 x 135.0

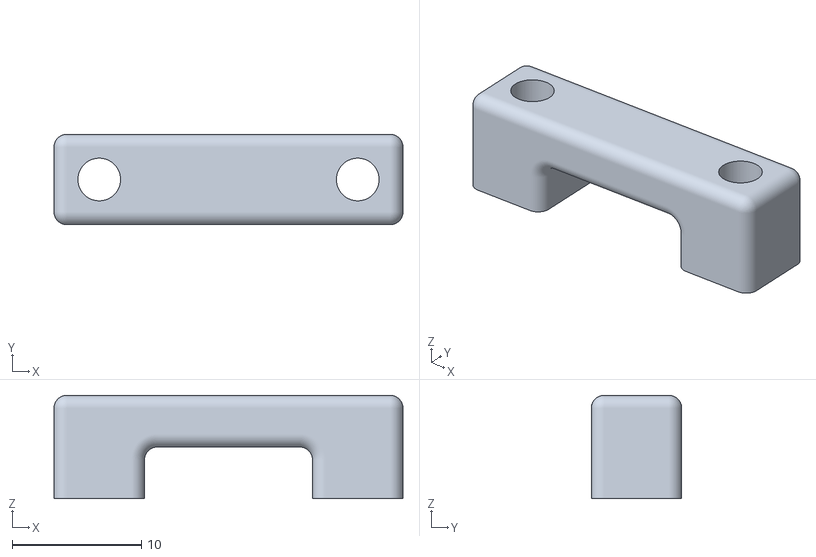
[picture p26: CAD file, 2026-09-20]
CAD/Frame - Cable guide.stl
27.0 x 7.00 x 8.00

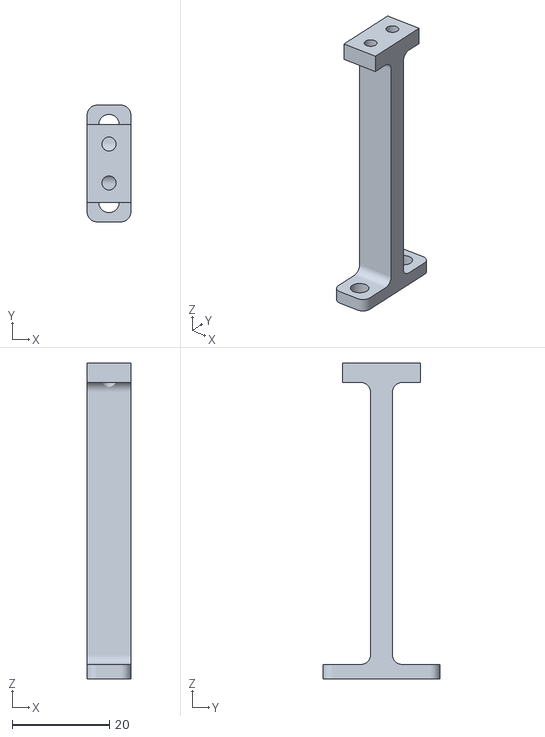
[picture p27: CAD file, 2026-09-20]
CAD/cableChain Post.stl
9.00 x 24.0 x 65.0

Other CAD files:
CAD/Frame - Rear Bearing clamp.stl
CAD/Frame - Front bearing clamp.stl
CAD/56T pulley - Bumper pulley L.stl
CAD/Board 18 mm.step
CAD/56T pulley - HTD-5M-56.stl
CAD/56T pulley - Yoke Column Clamp.stl
CAD/56T pulley - spacer.stl
CAD/AS5600 bracket - pitch.stl
CAD/AS5600 bracket - roll.stl
CAD/BTS7960 Standoff.stl
CAD/Belt Clamping Plate.stl
CAD/Board 18 mm.f3d
CAD/Case - Left front.stl
CAD/Case - Left rear.stl
CAD/Case - Right cover front.stl
CAD/Case - Right cover rear.stl
CAD/Case - Right front.stl
CAD/Case - Right rear.stl
CAD/Case - Shaft slide.stl
CAD/Case - dowel.stl
CAD/Case assembly 18mm.f3d
CAD/Frame - Bumper frame R.stl
CAD/Frame -Tube Clamp.stl
CAD/Frame.stl
CAD/Magnet mount - pitch.stl
CAD/PCB Standoff.stl
CAD/Pitch Pulley Mount L.stl
CAD/Pitch Pulley Mount R.stl
CAD/Rail mount helper.stl
CAD/Yoke Controller - Hat Mount.stl
CAD/Yoke Controller - Console Back.stl
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

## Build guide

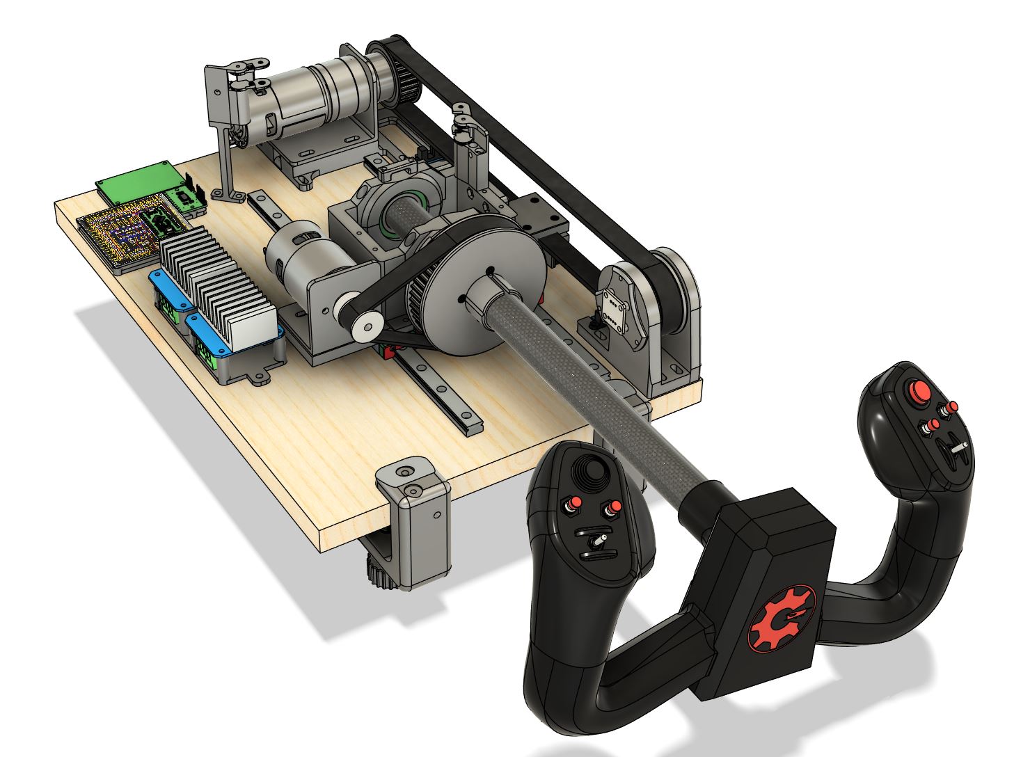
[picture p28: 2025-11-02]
Images/CAD/Yoke assembly-front.jpg

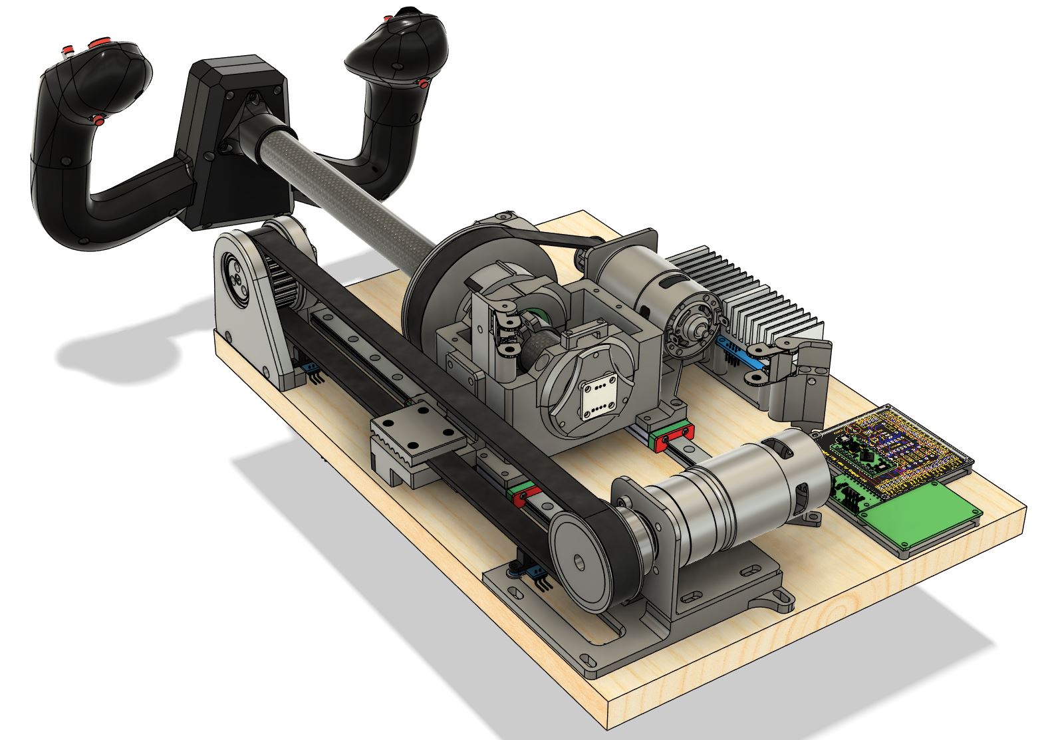
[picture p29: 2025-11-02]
Images/CAD/Yoke assembly-back.jpg

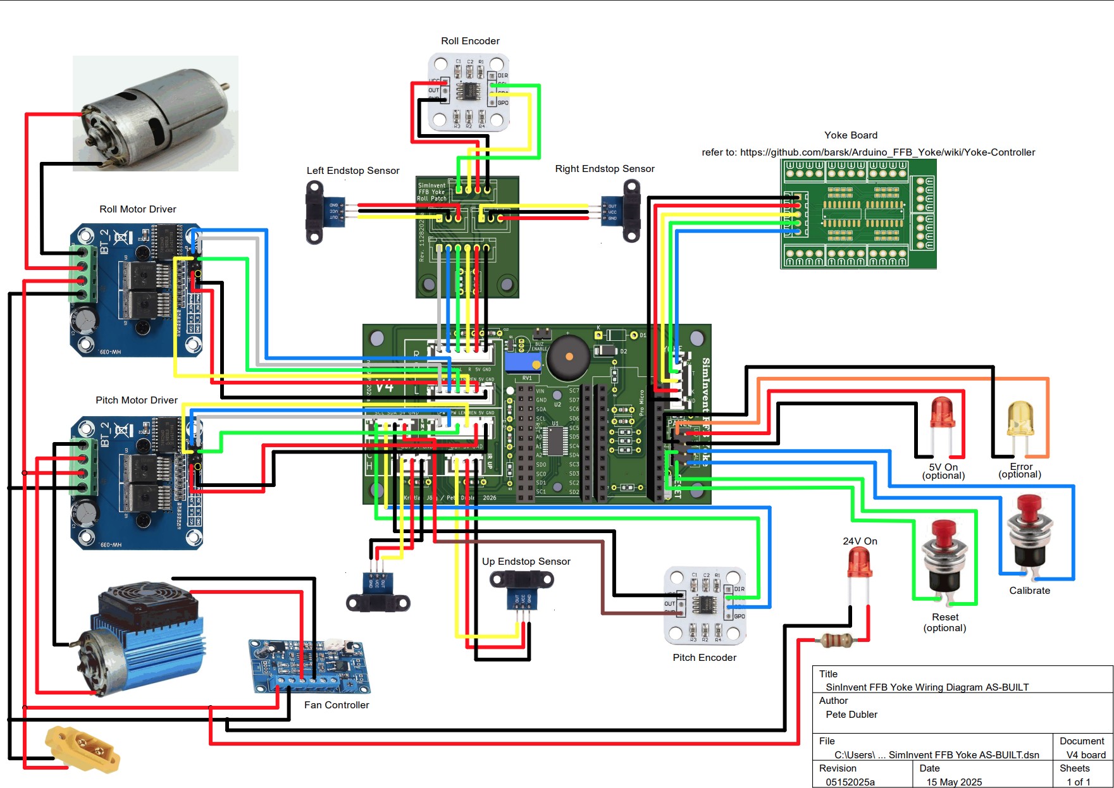
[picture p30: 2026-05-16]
Electronic/Wiring_Diagram/wiring-sketch.jpg

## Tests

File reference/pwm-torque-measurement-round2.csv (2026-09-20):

SimInvent FFB Yoke - PWM vs torque bench measurement - ROUND 2 (pitch only, push direction)
Semicolon-separated, decimal comma (SV)
Date | 2026-09-12
Measured by
Scale (make / resolution)
PSU (make / model)
PSU rating (A) | 20
Supply nominal (V) | 24
Ambient (C)
Round 1 | pwm-torque-measurement.csv - both axes, PSU-limited above magnitude ~6000. Its pitch push readings are copied below for comparison.
Run history | A first attempt at this round was discarded. Its low-end readings were inconsistent and the pitch belt was found to be over-tensioned. The belt was slackened before these readings. Only the V column is kept from that attempt - the supply behaved the same.
REQUIRED SETUP - all of these, or the numbers mean nothing
defines.h | PWM_KNEE_FORCE 0
defines.h | ENABLE_FRICTION_FF commented out
defines.h | ENABLE_SPEED_LIMITER stays off
Yoke Tool | Motor Start PWM = 0 (pitch)
Yoke Tool | Pitch Gain = 100 (default is 45)
FFBTestTool | Background spring UNTICKED (defaults to on at 8000)
FFBTestTool | Constant Force, duration infinite, push button = 180 deg (nose-down)
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

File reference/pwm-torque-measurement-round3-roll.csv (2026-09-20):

SimInvent FFB Yoke - PWM vs torque bench measurement - ROUND 3 (roll, top end)
Semicolon-separated, decimal comma (SV)
Date | 2026-09-12
Measured by
Scale (make / resolution)
PSU (make / model)
PSU rating (A) | 20
Supply nominal (V) | 24
Ambient (C)
Purpose | Round 1 measured roll on a 10 A supply that folded back to ~12 V above magnitude 7000, so everything it says about roll above 6000 is really about the PSU. This re-measures that range on the 20 A supply.
Comparable | The roll drivetrain has NOT been touched since round 1 - the belt that was slackened is on pitch. So round 1's roll readings below 6000 are still valid, and the 4000 / 5000 anchor rows below should reproduce them. If they do not, the rig or the method has drifted and the rest is suspect.
Pitch for reference | Round 2 (pitch, 20 A, cold): 4,42 kg at magnitude 10000 = 43,4 N at the handle.
REQUIRED SETUP - all of these, or the numbers mean nothing
defines.h | PWM_KNEE_FORCE 0
defines.h | ENABLE_FRICTION_FF commented out
defines.h | ENABLE_SPEED_LIMITER stays off
Yoke Tool | Motor Start PWM = 0 (roll)
Yoke Tool | Roll Gain = 100 (default is 70)
FFBTestTool | Background spring UNTICKED (defaults to on at 8000)
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

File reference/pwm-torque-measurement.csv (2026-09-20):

SimInvent FFB Yoke - PWM vs torque bench measurement
Semicolon-separated, decimal comma (SV)
Date
Measured by
Scale (make / resolution)
PSU rating (A) | 10
Supply nominal (V) | 24
Ambient (C)
REQUIRED SETUP - all of these, or the numbers mean nothing
defines.h | PWM_KNEE_FORCE 0
defines.h | ENABLE_FRICTION_FF commented out
defines.h | ENABLE_SPEED_LIMITER stays off
Yoke Tool | Motor Start PWM = 0 (both axes)
Yoke Tool | Roll Gain = 100 and Pitch Gain = 100 (defaults are 70 / 45)
FFBTestTool | Background spring UNTICKED (defaults to on at 8000)
FFBTestTool | Constant Force, duration infinite
Position | Mid-travel, clear of the soft-lock cushion and endstops
Method | Tap the frame and let it settle before each reading
GEOMETRY
Roll (X) | 12T to 56T = 4,67:1, handle lever 98 mm
Roll conversion | Nm at motor = kg * 9,81 * 0,098 / 4,67
Pitch (Y) | HTD-5M 14T driving pulley, r = 11,14 mm, carriage direct (no lever)
Pitch conversion | Nm at motor = kg * 9,81 * 0,01114
WARNING | Stalled 775 at high duty draws tens of amps. Keep each point 1-2 s.
WARNING | Stop at magnitude 7000 on the first pass. Add 8500 / 10000 only if the curve is already bending.
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

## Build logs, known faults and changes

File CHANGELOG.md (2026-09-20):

# Changelog

Notable changes to the SimInvent FFB Yoke firmware and the Yoke Tool.

Versions here describe the **firmware**; the Yoke Tool ships alongside it and is
noted where it changed. Figures are measured on the SparkFun Pro Micro
(ATmega32u4) build .

---

## [1.0-RC1] - 2026-09-19

Release candidate. The force loop runs about **three times as fast** under a full
effect load, multi-second FFB command lag is gone, several effect bugs that only
appeared under that load are fixed, and the low end - where stiction rather than
the force command decides what the pilot feels - was rebuilt around measurements.

Most of this came out of driving the yoke from SimInvent-TelemFFB over DirectInput, which
stacks 10-17 simultaneous effects and reached problems that bench testing with
one or two effects never did. The later half came out of tuning the condition
effects against it: damper, friction and inertia are all derived from encoder
position, and nearly every fault found there was a constant that silently
depended on the loop rate.

The pitch drivetrain is selectable, so the earlier planetary-gear build is
supported by a one-line edit.

### Force feedback correctness

- **Effects no longer cancel or distort each other under load.** `forceCalculator`
  summed every playing effect into an `int16_t`. A full MSFS aircraft puts 10+
  effects on the pitch axis (G-force, elevator droop, AoA, deceleration and
  touchdown all pull the same way), so the sum wrapped past +/-32767 *before* the
  final clamp. Symptom: an effect did nothing while others played, but worked
  correctly on its own, and periodics went jerky. Now accumulated in `int32_t`,
  with the clamp applied only at the end.
- **Roll spring reaches full travel.** Roll's spring and condition effects
  saturated at roughly 29% of physical travel while pitch was fine: a pitch-only
  soft-lock margin was applied to roll, shrinking the spring's reference range
  without shrinking the reported HID axis range. Travel limits and soft lock are
  now handled uniformly for both axes, and the HID axis range and the spring's
  centre are set in lock-step so they cannot drift apart again.
- **The default spring was scaled by total gain twice.** The Settings Tool's default
  spring slider ran through `totalGain` inside its own calculation *and* again in the
  common gain stage that scales every effect, so it delivered **gain squared** - 49% on
  roll (gain 70) and 20% on pitch (gain 45) at a slider setting of 100%. Host-created
  spring effects pick up total gain only once and were unaffected, which is why the same
  spring felt right from a test tool and weak from the tool's own slider. Every other
  effect type applies only its own type gain; the default spring was the sole exception.
  **Upgrading: the default spring is now stronger** - about 1.4x on roll and 2.2x on
  pitch - so a setting that felt right before is roughly the old value multiplied by that
  axis's total gain (pitch 100% -> about 45%).
- **PID layer reviewed against the USB PID 1.0 specification** and all discrepancys fixed.
- **Triangle and Sawtooth** agree in direction with Constant, Sine and Square.
- **Effect direction now correctly follow the DirectInput convention** - an effect's direction
  is where the force *comes from*, and the applied force is its opposite. This was previously handled **inverted**.
  Verified against a spec-compliant commercial FFB wheel and against SimInvent-TelemFFB's own usage.

### Latency

- **Multi-second FFB command lag removed.** Latency grew with time in flight and
  with high effect count, and could cause seconds of lag. Cause: the USB
  interrupt OUT endpoint is double-banked, so one `RecvfromUsb()` accepts at most
  two reports - and it ran **once per main-loop pass**. Delivery was capped at
  twice the loop rate, so any surplus queued host-side and grew for as long as
  the demand lasted. The endpoint is now drained at three points per pass, around
  the slow I2C encoder and button reads.
- **A stalled position report can no longer stall the force loop.** The Arduino
  core's `USB_Send()` blocks - it spins in `delay(1)` for up to 250 ms while the
  IN bank is still full - and joystick position was sent ahead of the effect
  update on every pass. A position report is worthless once superseded, so it is
  dropped when the bank is busy rather than waited on.
- **A stray byte on the serial port no longer freezes the yoke.**
  `Stream::readBytes()` defaults to a 1000 ms timeout, so a single noise byte
  (port enumeration, a leftover serial monitor, another tool scanning ports)
  blocked the settings read for a full second, every 100 ms. Capped at 15 ms; a
  real command's bytes arrive within about 1 ms.

### Performance

Force-loop rate at a matched effect count, which is also the FFB update rate:

| effects | 0.9 | 1.0-RC1 |
|---|---|---|
| 10-11 | 80-96 Hz | **248-260 Hz** |
| 15-16 | ~80 Hz | **196-208 Hz** |
| idle | ~850 Hz | **~980 Hz** |

- **Sine lookup table replaces `sin()` in the force loop** - a 65-entry quarter
  wave in PROGMEM, Q15, linearly interpolated. `avr-libc`'s `sin()` costs about
  150 us per call in software float and was the largest single cost in the loop.
  Worth roughly **+45%** loop rate on its own, measured against the previous
  build. Interpolation is not optional here: nearest-point lookup leaves a 4.7%
  amplitude staircase, twelve times coarser than the 8-bit PWM output can
  resolve, and it is felt in periodic effects. Interpolated, worst-case error is
  0.0095% - about 40 times finer than the output stage - verified exhaustively
  across all 65536 phase values.
- **Direction projection cached** rather than recomputed per effect per axis, and
  only the component the effect type actually reads is calculated.
- **Float divides removed from the hot path.** Per-effect and per-axis gains use
  a reciprocal multiply, and the condition calculator does the same for its fixed
  scale factors. A float divide is roughly 400 cycles on AVR.
- **Envelope fast path** for the common case of no attack and no fade.
- Assorted hoisting in `forceCalculator`: `millis()` read once per pass, an early
  exit for effects that are not playing, and a guarded modulo in place of an
  unconditional 32-bit division.
- **Constant and periodic waveforms are computed once per effect**, not once per
  axis. The calculator, the envelope and their 32-bit divides ran twice over for
  the same number; only the per-axis gain and direction actually differ. The
  per-type gain is now indexed by effect type, guarded by a compile-time check on
  the `Gains` field order. Output is bit-identical.
- **Two more 32-bit divides removed from the per-effect path.** The phase offset
  skips its divide when phase is 0 - nearly every effect TelemFFB sends - and the
  envelope fast path tests `magnitude * gain >= 255` instead of dividing by 255 to
  compare the result with zero. Same predicates, about 33 us each.
- The idle figure above comes from the encoder read in *Position sensing*; the
  rest is these two changes.

### Motor drive

Five changes attacking the same problem from different sides: what the axis does
at very small forces, where dry friction rather than the force command decides
what the pilot feels. This adresses the problems associated with the "Motor Start PWM" 
value from the Yoke Settings Tool. When clamping the usable pwm values to start from a 
higher value to counter the non linear response of a 775 DC motor it means we solve the 
problem of getting the motor to move at low stimuli, but we also get a raised response 
for the whole lower end of forces. This means small forces get unrealistically amplified, 
strong forces work fine. The settings below are used to counter this and create a more
linear feel in the lower force range.

- **Low-end linearity: the breakaway knee.** PWM stepped straight to `pwmMin` 
  (about 10% drive) the instant any force appeared - `map(|force|, 0, 10000,
  pwmMin, 255)` - so a 5% effect asked for 10% drive and the axis broke static
  friction with a lurch. Below `PWM_KNEE_FORCE` (1200 of 10000) the breakaway
  offset now eases in on a quadratic curve instead of stepping; at and above the
  knee the mapping is byte-for-byte the old one. `PWM_KNEE_FORCE 0` restores the
  previous behaviour. It stays on by default at `1200`: with Motor Start PWM near
  breakaway, turning it off would tighten the held dead band but let small forces
  such as propeller rumble ride the full offset - the inflation the knee was
  introduced to stop.
- **`PWM_KNEE_FLOOR_PCT` trades the knee's dead zone against a pop.** Ramping the
  offset from zero leaves the smallest commands below breakaway, so nothing moves
  at all: on its own the knee swaps a hard grab for a soft dead zone. The floor
  starts that ramp at a percentage of `pwmMin` instead. `0` is the full soft ramp
  (widest dead zone, no pop), `100` is exactly the old hard step, and `75`
  removes most of the dead zone while leaving a pop of only about
  `pwmMin * 0.2` counts as the axis frees. `80` is the default, settled by feel on
  the yoke.
- **Stribeck friction feedforward** (`ENABLE_FRICTION_FF`). Knee
  and floor can only trade one artefact for the other, because neither knows
  whether the axis is already moving. Static friction is far higher than kinetic,
  so the real fix is velocity-aware: a boost in the *commanded* direction,
  strongest at standstill and fading as `VS / (VS + |v|)`, using the velocity
  `applyForce()` is already given - no new sensing. Weak effects break the axis
  loose without a large standing offset, and the static-to-kinetic drop behind
  the pop is covered too. `FRIC_FF_STATIC` (6 PWM counts) is the peak boost, added
  on top of the knee mapping. What must stay below real breakaway is the drive the
  tiniest force gets - floor x Motor Start PWM plus the boost - or the axis crawls
  or hums hands-off near centre; with the defaults below that is 40 / 37 counts on pitch / roll,
  11 / 8 under measured breakaway. `FRIC_FF_VS` (200, in the speed
  limiter's `<< VEL_SHIFT` units) is the half-boost velocity, deliberately low so
  the assist stays near standstill; `FRIC_FF_MIN_FORCE` (40) gates out rounding
  noise. It used to crash and reboot the yoke. That was never the stack or memory:
  `COAST_AT_IDLE` released the bridge with current still in the winding, and
  friction feedforward, driving harder at small forces, made that happen far more
  often. The brake-before-coast below fixed it. *Hardware-confirmed stable with
  `COAST_BRAKE_MS` in place.*
- **Low-end defaults from measurement, settled by feel.** Bench sweeps on the 20 A
  supply (sheets in `reference/`) put breakaway at PWM 51 on pitch and PWM 45 on
  roll. The defaults were then tuned on the yoke with friction feedforward on:
  Motor Start PWM **43 pitch / 39 roll** (was 26 / 25), knee `1200`, floor `80`,
  `FRIC_FF_STATIC 6`. Motor Start PWM just under breakaway lets a held force reach
  movement early - modelled from the measured curves, the dead band falls from
  about 25% to 8% of the sim's force range on pitch and from 14% to 3% on roll -
  while the knee keeps small forces such as propeller rumble from riding the full
  offset. The tiniest force gets 41 / 38 counts, 10 / 7 under breakaway, so the
  yoke holds still near centre hands-off. Total gain defaults to **70 pitch / 100
  roll** (was 45 / 70). At the real 125 mm grip that leaves pitch about 1.25-1.45x
  roll's force for the same sim magnitude; a pitch gain near 40 would balance them.
  New defaults only reach a yoke with fresh or reset EEPROM; stored settings are
  kept.
- **The friction feedforward is set per axis.** `FRIC_FF_VS` is in encoder counts
  and `FRIC_FF_STATIC` in PWM counts, so both depend on the drivetrain and cannot
  be one shared number. They are now `FRIC_FF_*_ROLL` and `FRIC_FF_*_PITCH`; the
  pitch trio lives in the drivetrain block described below.
- **The bridge is released at idle** (`COAST_AT_IDLE`). With nothing commanded,
  `driveMotor()` left both bridge inputs low - motor terminals shorted, so the
  axis was electrically braked at rest. That dragged on every hand input and
  fought all of the above. `EN` now goes low at zero command and the axis coasts.
  Comment it out for the old always-braked behaviour, which settles more firmly
  hands-off.

  It brakes for a moment before letting go (`COAST_BRAKE_MS`, 10 ms). Releasing
  `EN` the instant the force reached zero dropped the bridge while the winding
  still carried current, and that current's only path was through the FETs' body
  diodes back into the 24 V rail. A switch-mode PSU cannot absorb it: on a 20 A
  supply, stopping a strong effect tripped the PSU's over-voltage protection
  every time, and the same spike exceeds the BTS7960's ~27 V rating. A 10 A
  supply had hidden it by capping the current, and with it the stored energy.
  Both low-sides are now held on for 10 ms first, so the current dies away inside
  the motor, and then the bridge is released as before. Comment it out to restore
  the instant release. *Hardware-confirmed: the PSU no longer trips on stop.*
  The same release had been crashing the yoke whenever friction feedforward was
  on, and the brake cured that too - so keep `COAST_BRAKE_MS` whenever
  `ENABLE_FRICTION_FF` is enabled.

The knee, floor, friction feedforward and coast settings are compile-time in
`defines.h` rather than settings-struct fields, so retuning them costs no
`FIRMWARE_VERSION` bump. Motor Start PWM and gain are per-axis Yoke Tool settings
stored in EEPROM; the values above are their defaults. *Bench-measured on the
775-motor build - confirm by feel.*

### Position sensing

- **The angle the force loop reads is about 8x fresher.** The AS5600 powers up with
  its slow filter at 16x, which settles in **2.2 ms** - roughly a whole loop pass of
  lag on every position that the spring, damper, friction and inertia are derived
  from. `ENCODER_SLOW_FILTER` sets it to 2x: **0.286 ms**, at the cost of RMS noise
  rising from 0.015 to 0.043 degrees, still under half of one 12-bit count. The
  config register is volatile, so it is re-applied at every boot.
- **One I2C transaction less per axis per pass.** The datasheet (v1-06) exempts
  ANGLE, RAW ANGLE and MAGNITUDE from the address-pointer auto-increment while the
  pointer sits on the register's high byte, so a re-read needs no pointer write.
  `FastAS5600` skips it, taking a full read every eighth read and after any I2C
  error - which bounds how long a sensor that reset on its own could be misread.
  Worth about 130 Hz at idle.
- **Velocity, acceleration and the friction delta are measured over a fixed
  window.** They were differentiated per loop pass, which tied all three to the
  loop rate: one encoder count of jitter read as 64 velocity / 640 acceleration
  units at ~1 kHz idle against 16 / 40 at ~250 Hz in flight. Damper, inertia and
  friction therefore changed character with effect count, and inertia was mostly
  differentiated noise. `PHYSICS_SAMPLE_MS` (10 ms) pins it: the jitter floor is
  6.4 units for both, whatever the loop is doing. **The `*MaxVelocity`,
  `*MaxAcceleration` and `*MaxPositionChange` references are in those units**, so a
  custom value has to be rescaled if the window is changed.

### Condition effects

- **Damper, inertia and friction no longer soften as effects stack up.** Their
  output filter applied a fixed step per pass derived from an assumed 500 Hz loop,
  so the real cutoff followed the loop rate: about 3.9 Hz at idle, 1.0 Hz at ten
  effects, 0.79 Hz at fifteen - a 5x spread, and never the 2 Hz it claimed. The
  coefficient is now derived from the **measured** loop period, 16 times a second.
  Damper and friction hold a ~15 ms time constant across the whole range where they
  used to vary between 41 and 202 ms; inertia holds ~41-45 ms.
- **Each effect type has its own cutoff** - `DAMPER_LPF_HZ` and `FRICTION_LPF_HZ` at
  12 Hz, `INERTIA_LPF_HZ` at 8 Hz. Damper and friction should track the hand, and
  that lag is what made a quick jab feel weaker than a steady sweep at the same
  speed. Acceleration is a second difference of a quantised position, so inertia
  keeps more smoothing.
- **No burst of vibration when a host connects.** The filters were left unconfigured
  until the first measurement window, which put raw, unfiltered damper force on the
  motors for a fraction of a second - enough to buzz the yoke audibly. They are now
  seeded at startup for the fastest loop the firmware reaches, and the window is
  measured whether or not a host is driving effects.
- **A latent way to lose damper, inertia and friction entirely.** A
  default-constructed filter had a coefficient of 0, which is not "unfiltered" but
  "output frozen at zero". Nothing ever hit it, because `begin()` always configured
  the filters first, but the default is now pass-through.
- **Inertia references were about 10x too high.** They carried the `<< VEL_SHIFT`
  shorthand that belongs to the velocity references, so inertia saturated only on
  the initial jerk of a movement and went quiet through the rest of it. They are
  plain acceleration numbers now, with the rule of thumb in `defines.h`.

### Pitch drivetrain

- **`NEW_PITCH_CONF_14T` selects the drivetrain.** `true` is the current 14T pulleys
  with no planetary gear; `false` is the previous two 30T pulleys with the 1:3.7
  planetary. It is a plain edit in `defines.h`, so the Arduino IDE needs no build
  flags, and everything that differs between the two sits in one block. The 30T
  column is scaled from the measured 14T values by two ratios: **x0.47** on
  everything count-based - the encoder magnet rides the idler pulley, so 4096 counts
  span one belt circumference, 70 mm on 14T against 150 mm on 30T - and **x0.58** on
  everything force-based, 3.7/23.87 mm against 1/11.14 mm at the carriage. Those
  figures are derived, not measured on that hardware. **Switching drivetrain:
  re-run calibration**, since stored travel is in encoder counts and the scale
  changes, and reset the Settings Tool to defaults, since pitch gain and Motor Start
  PWM live in EEPROM and the compile-time values only seed a fresh one.

### Defaults shipped in RC1

Compile-time, in `defines.h`, unless the table says otherwise.

| Setting | Roll | Pitch (14T) | Pitch (30T + 1:3.7) |
|---|---|---|---|
| Motor Start PWM *(Settings Tool, EEPROM)* | 39 | 43 | 25 |
| Total gain *(Settings Tool, EEPROM)* | 100 | 70 | 40 |
| `default_damperMaxVelocity_*` | `5 << VEL_SHIFT` | `24 << VEL_SHIFT` | `11 << VEL_SHIFT` |
| `default_frictionMaxPositionChange_*` | 50 | 200 | 93 |
| `default_inertiaMaxAcceleration_*` | 140 | 500 | 233 |
| `MAX_VELOCITY_*` | `15 << VEL_SHIFT` | `25 << VEL_SHIFT` | `12 << VEL_SHIFT` |
| `FRIC_FF_STATIC_*` | 6 | 6 | 3 |
| `FRIC_FF_VS_*` | 200 | 200 | 94 |
| `FRIC_FF_MIN_FORCE_*` | 40 | 40 | 40 |

Shared by both axes: `PWM_KNEE_FORCE 1200`, `PWM_KNEE_FLOOR_PCT 80`,
`PHYSICS_SAMPLE_MS 10`, `ENCODER_SLOW_FILTER 3` (2x), `DAMPER_LPF_HZ 12`,
`FRICTION_LPF_HZ 12`, `INERTIA_LPF_HZ 8`, `COAST_AT_IDLE` with `COAST_BRAKE_MS 10`,
`ENABLE_FRICTION_FF` on, default effect gain 100 and default spring gain 50.

### Memory and build

| build | flash | free | RAM |
|---|---|---|---|
| release | 27 848 / 28 672 | 824 | 2 125 / 2 560 |
| `FFB_SERIAL_TRACE` | 28 606 | 66 | 2 145 |
| `FFB_STACK_TRACE` | 28 598 | 74 | 2 145 |
| both together | 29 184 | **does not fit** | - |

- **HID report descriptor frozen into PROGMEM.** The joystick half was rebuilt
  byte-by-byte at every boot into a 150-byte RAM buffer that then stayed
  allocated for the life of the device - to re-derive a constant. Now an 84-byte
  PROGMEM array, verified two independent ways against the builder's output.
  **-150 bytes RAM, -314 bytes flash.**
- **Linker relaxation enabled** (`-Wl,--relax`, via `relax.py`), converting
  `call`/`jmp` to `rcall`/`rjmp` where the target is in range. PlatformIO does
  not forward this from `build_flags` to the link step, hence the pre-script.
  **-558 bytes flash.**

### Diagnostics and tooling

- **Build identity is queryable.** The Yoke Tool shows which firmware is running
  - variant name plus compile date and time - in its status bar on connect and on
  every Read. New `<BI>` command in the settings protocol, and a `FW_VARIANT`
  string in `defines.h` to bump per build. Deliberately a query rather than a
  banner: the port is shared with the tool, so anything the firmware volunteers
  would land in the middle of that conversation. Compatible in both directions -
  an older tool never sends `<BI>`, and older firmware simply does not answer.
- **`FFB_SERIAL_TRACE` build** emits a compact CSV trace of effect operations plus
  a 4 Hz force-loop line,
  `F<nPlaying>,<rxReports>,<loops>,<fxPeak>,<fyPeak>,<vxPeak>,<vyPeak>`. `loops` x4
  is the loop
  rate, `rxReports` x4 shows how close USB delivery is running to its drain
  ceiling. `fxPeak`/`fyPeak` are the peak per-axis force over the window, exactly
  as handed to the motor stage, and `vxPeak`/`vyPeak` the peak axis velocity in the
  units the `*MaxVelocity` and `*MaxAcceleration` references use - peak against
  peak, which is what makes them comparable and what those references are set
  against. Field legend in `defines.h`.
- **Stack instrumentation is `FFB_STACK_TRACE` only.** The stack paint, its 50 ms
  scan, the EEPROM watermark and the `S` line that reports them - including
  `prevMin`, the post-mortem reading from the session *before* a crash - no longer
  build into the serial-trace configuration. Stack was ruled out as the cause of
  those resets (it was the bridge release, see *Motor drive*), and the two trace
  builds no longer fit in flash together.
- The development-only `FFB_PROFILE` probe was removed once its questions were
  answered. `platformio.ini` records what it measured, so it does not get rebuilt
  to re-answer them.

---

## [0.9]

Initial beta release.

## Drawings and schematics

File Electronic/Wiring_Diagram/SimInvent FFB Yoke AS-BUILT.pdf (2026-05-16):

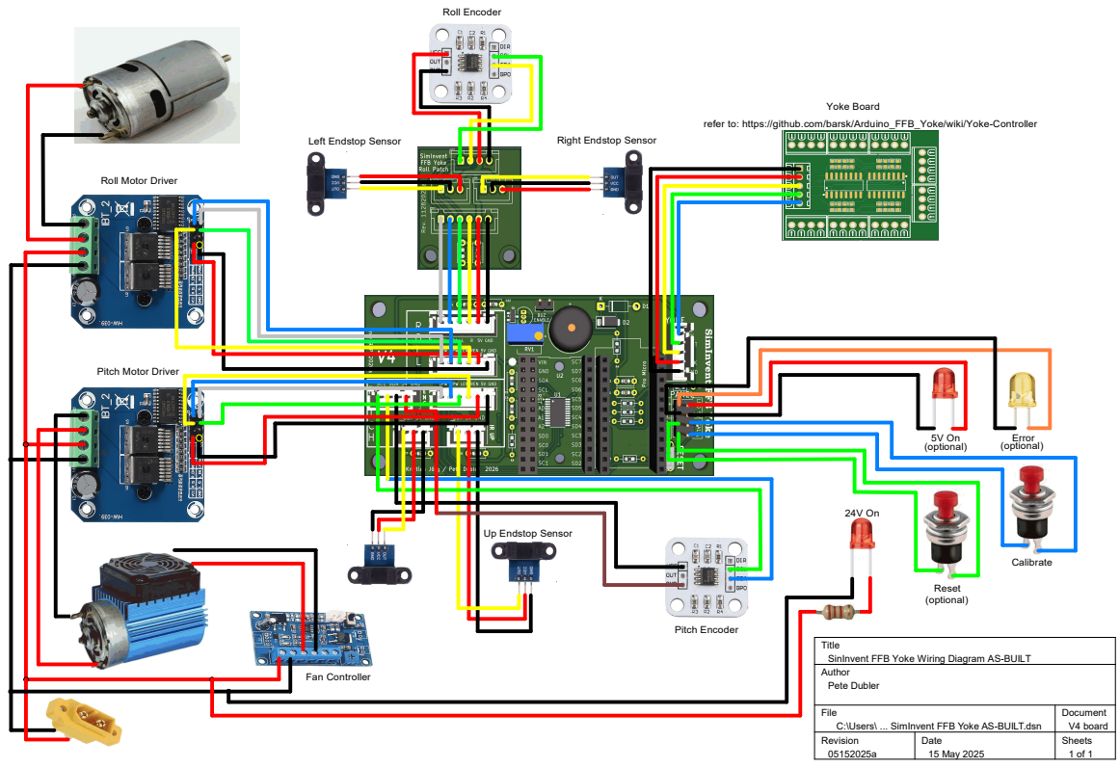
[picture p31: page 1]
Left Endstop Sensor; Right Endstop Sensor; Fan Controller; Pitch Encoder; Roll Encoder; Error; Calibrate; Reset (optional); (optional); Yoke Board

refer to: https://github.com/barsk/Arduino_FFB_Yoke/wiki/Yoke-Controller

Roll Motor Driver

Pitch Motor Driver

Up Endstop Sensor

Title
SinInvent FFB Yoke Wiring Diagram AS-BUILT
Author
Pete Dubler

File C:\Users\ ... SimInvent FFB Yoke AS-BUILT.dsn | Document V4 board

Revision 05152025a | Date 15 May 2025 | Sheets 1 of 1

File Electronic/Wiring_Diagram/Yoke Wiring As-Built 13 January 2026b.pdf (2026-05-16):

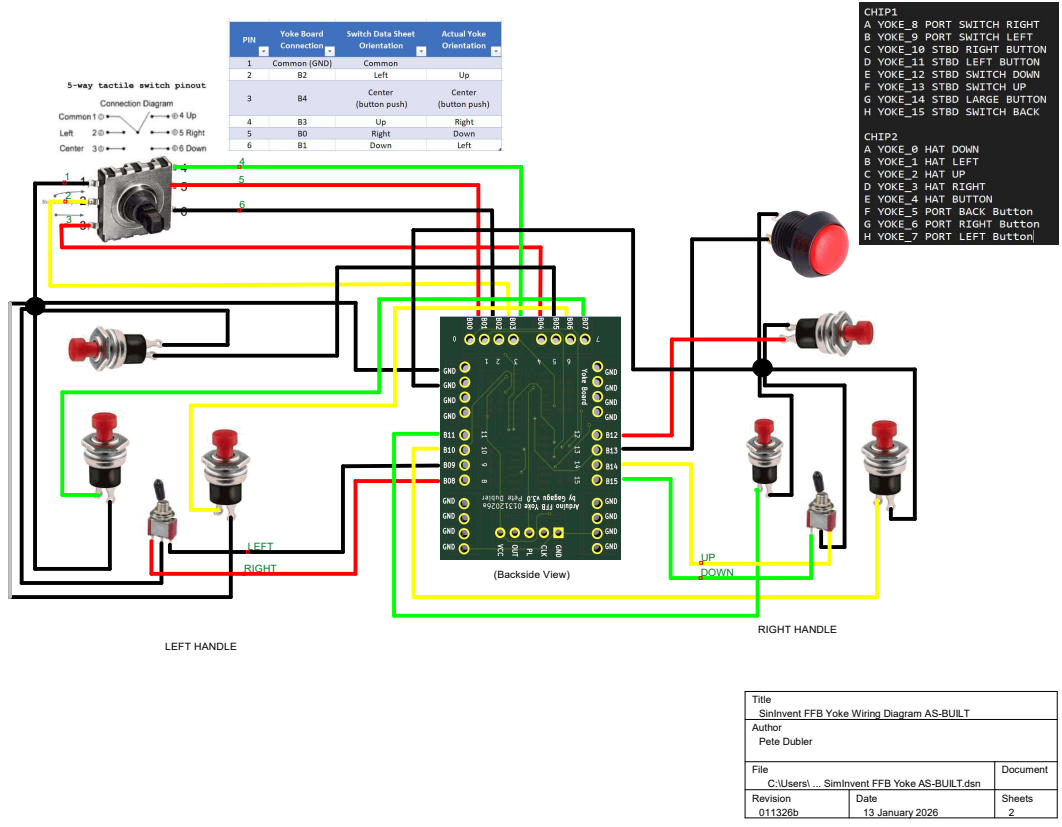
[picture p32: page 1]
LEFT HANDLE; RIGHT HANDLE; (Backside View) conn⁻3; conn⁻4; UP DOWN; LEFT; RIGHT

Title
SinInvent FFB Yoke Wiring Diagram AS-BUILT
Author
Pete Dubler

File C:\Users\ ... SimInvent FFB Yoke AS-BUILT.dsn | Document

Revision 011326b | Date 13 January 2026 | Sheets 2

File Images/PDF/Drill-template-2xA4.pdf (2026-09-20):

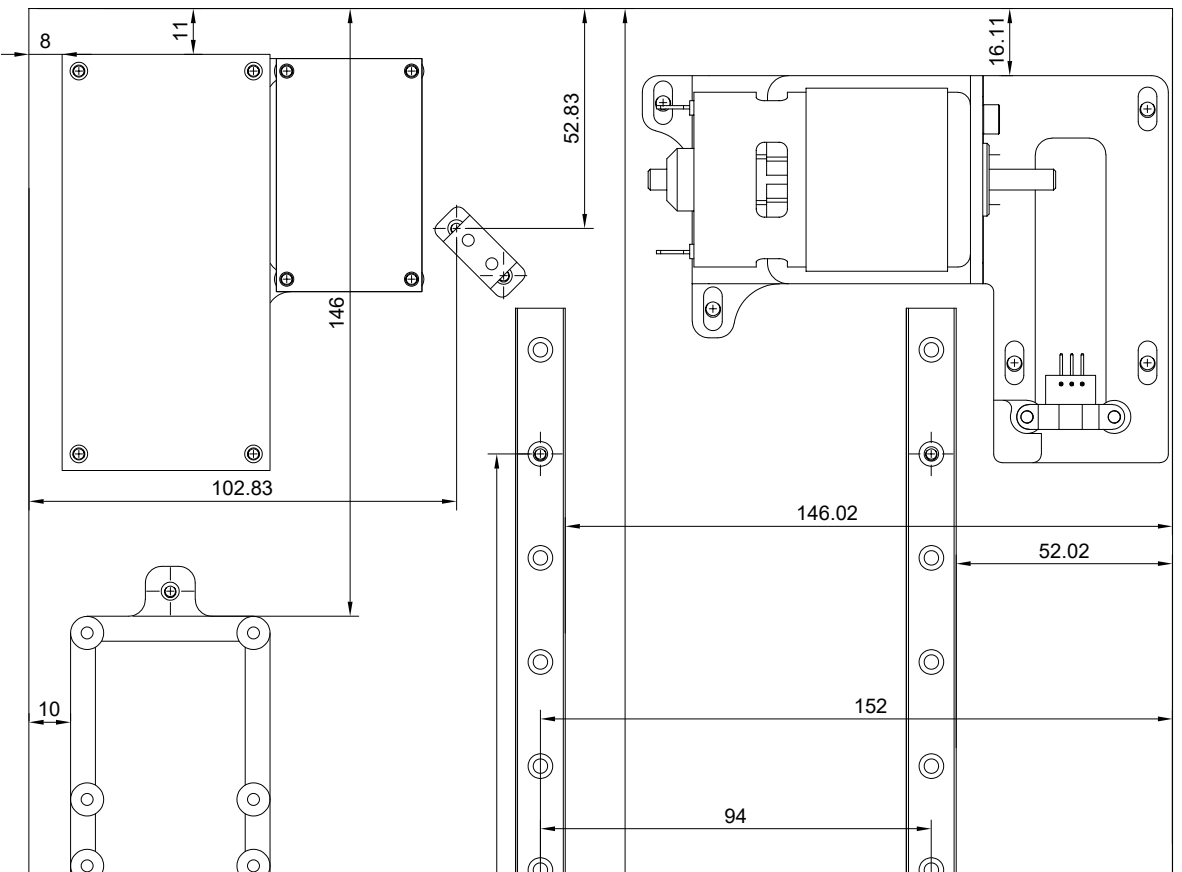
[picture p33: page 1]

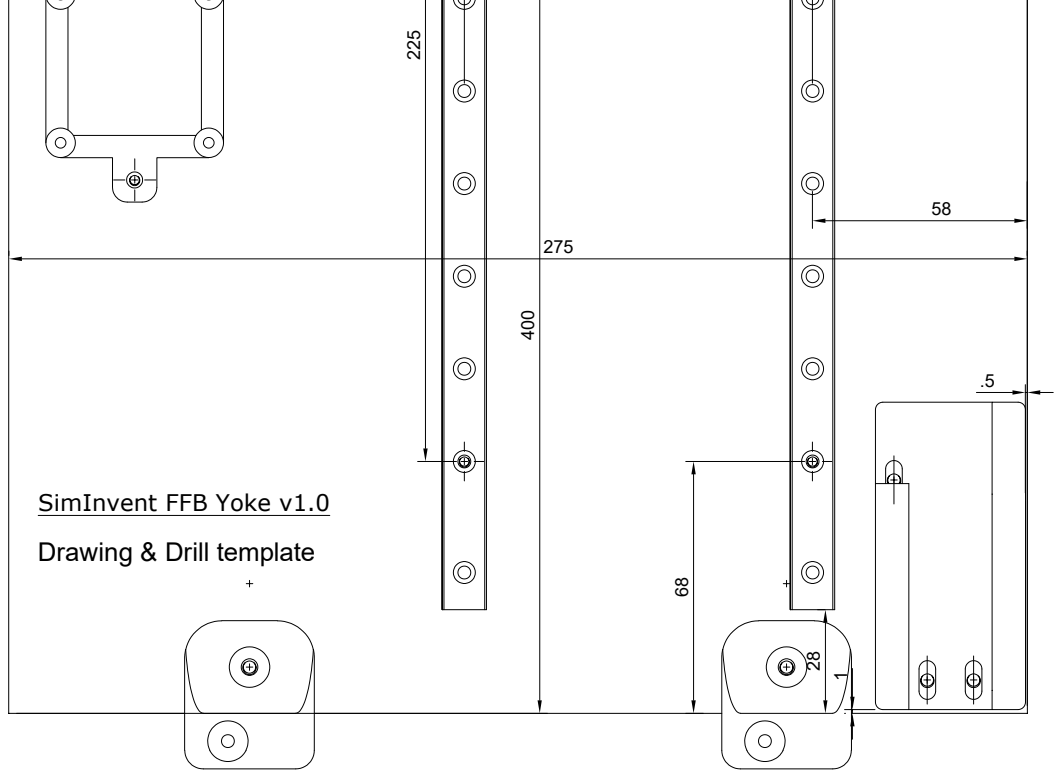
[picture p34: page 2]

SimInvent FFB Yoke v1.0
Drawing & Drill template

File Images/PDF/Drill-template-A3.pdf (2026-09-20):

# 94 ¹⁴⁶

146.02 ⁵².83

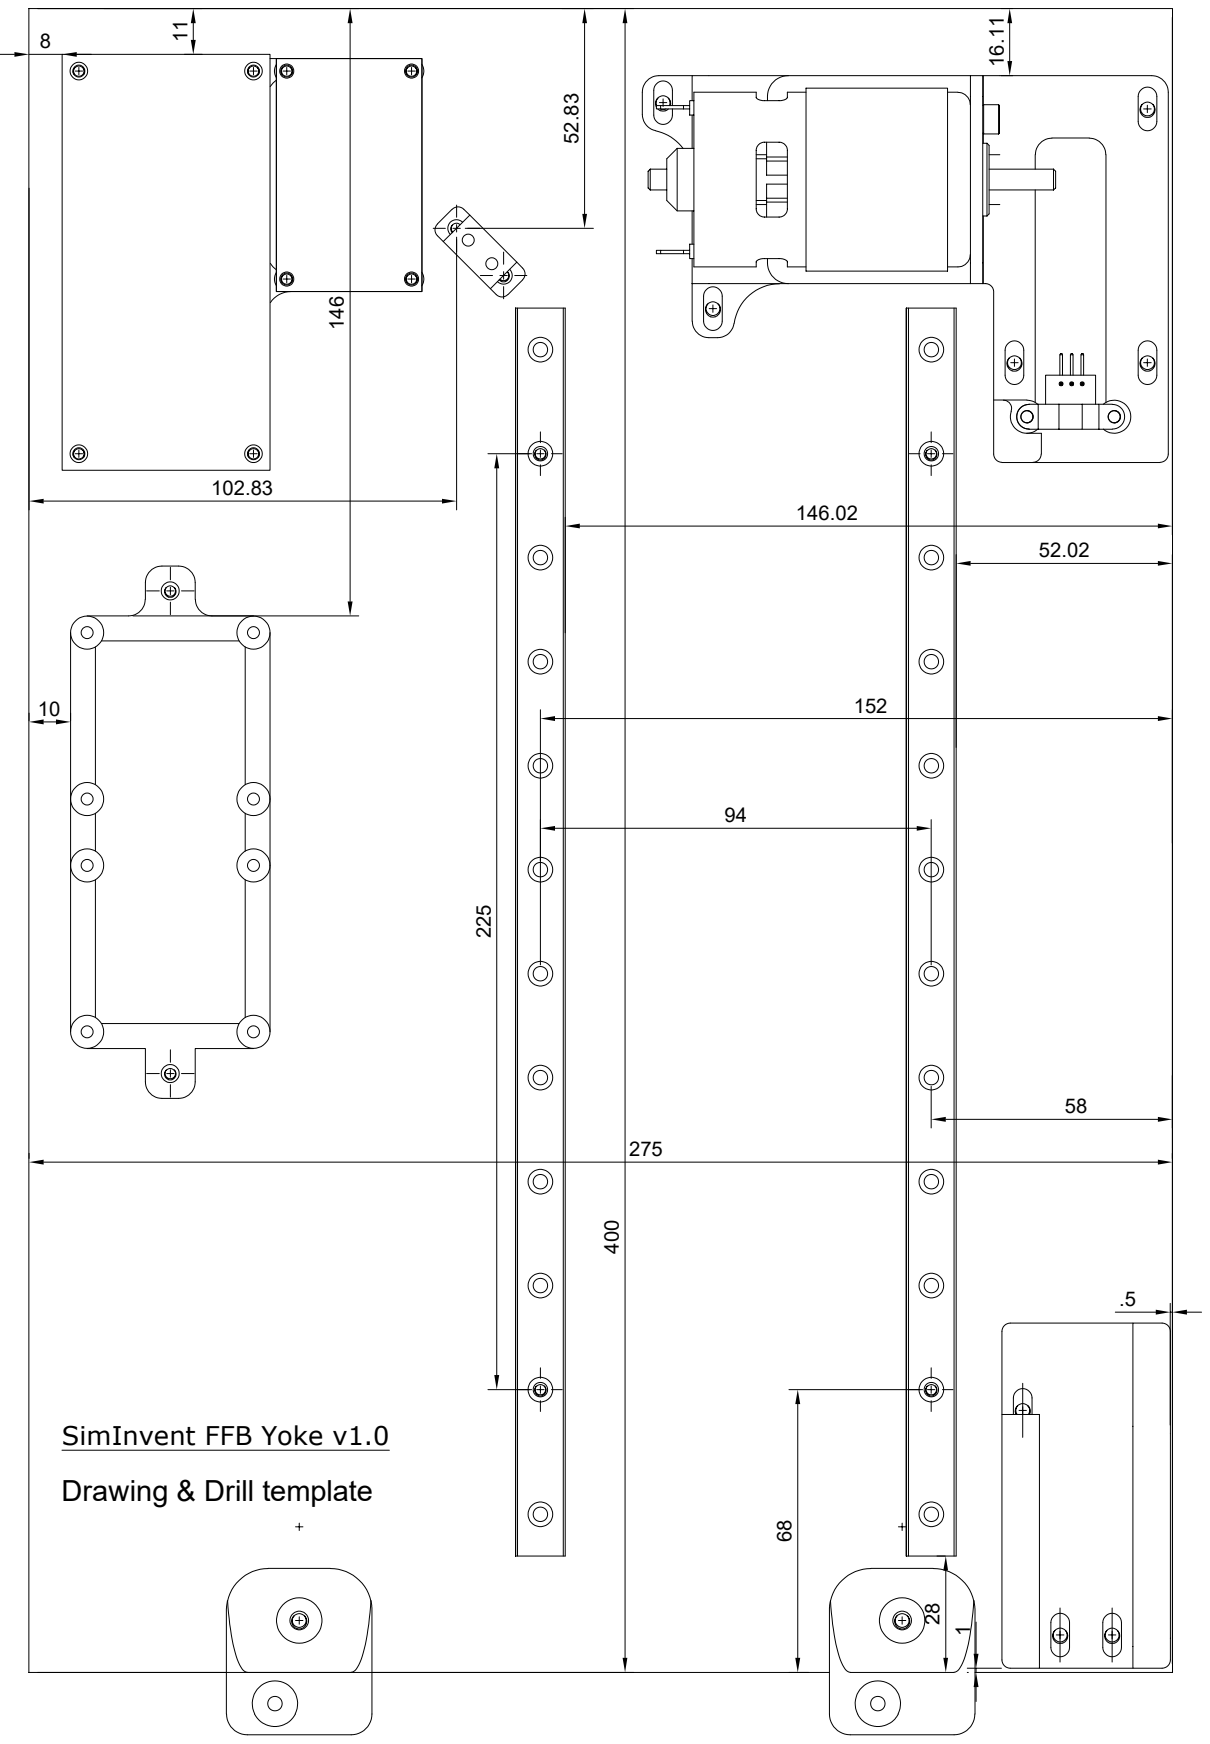
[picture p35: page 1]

SimInvent FFB Yoke v1.0
Drawing & Drill template

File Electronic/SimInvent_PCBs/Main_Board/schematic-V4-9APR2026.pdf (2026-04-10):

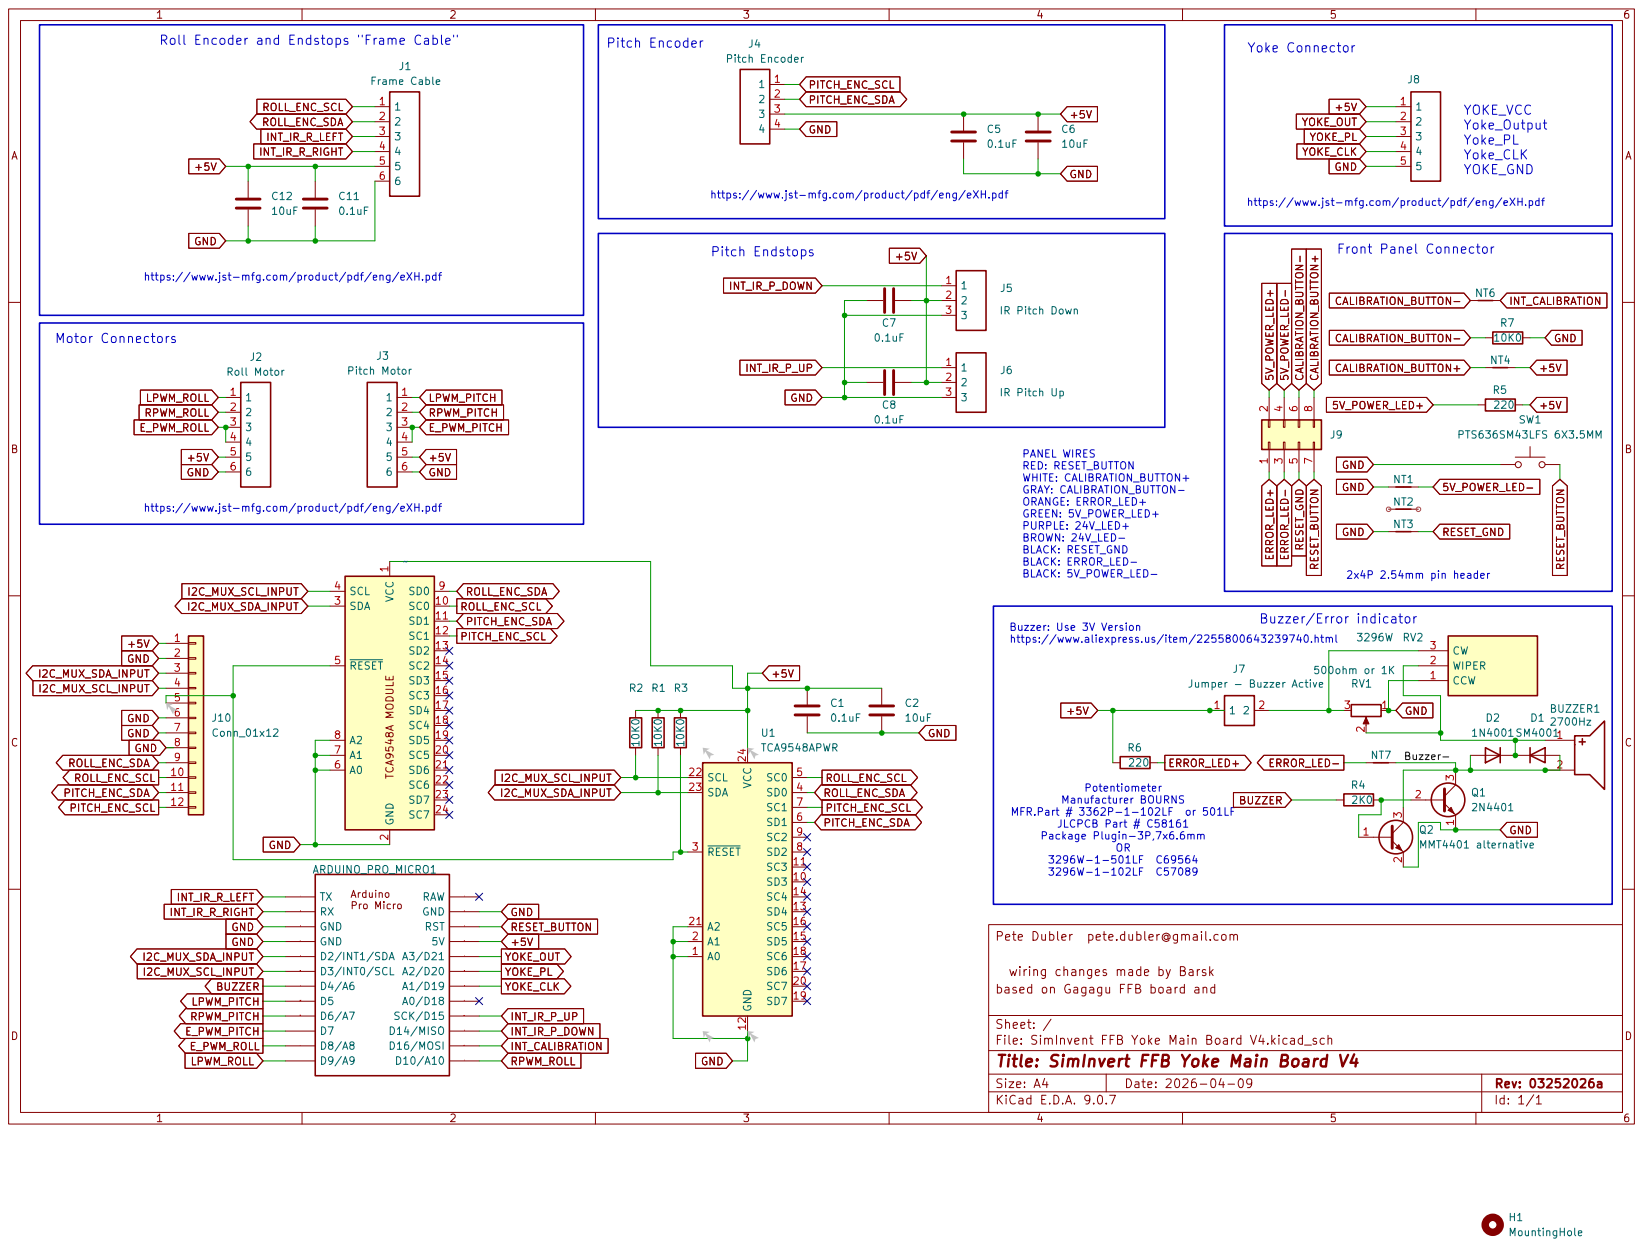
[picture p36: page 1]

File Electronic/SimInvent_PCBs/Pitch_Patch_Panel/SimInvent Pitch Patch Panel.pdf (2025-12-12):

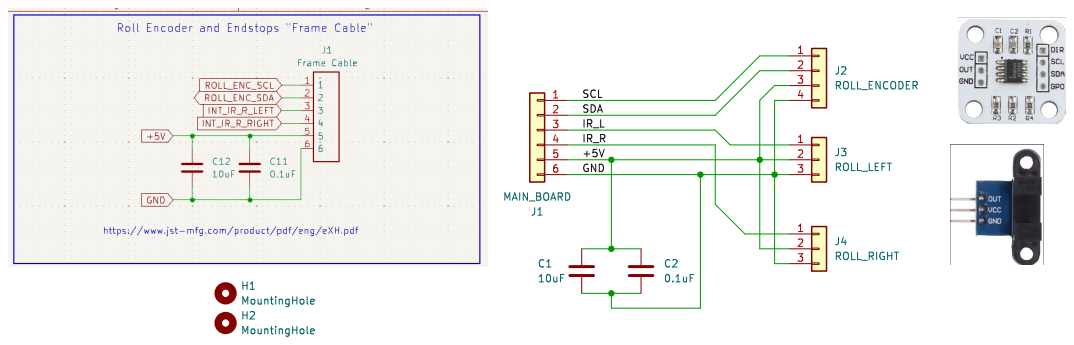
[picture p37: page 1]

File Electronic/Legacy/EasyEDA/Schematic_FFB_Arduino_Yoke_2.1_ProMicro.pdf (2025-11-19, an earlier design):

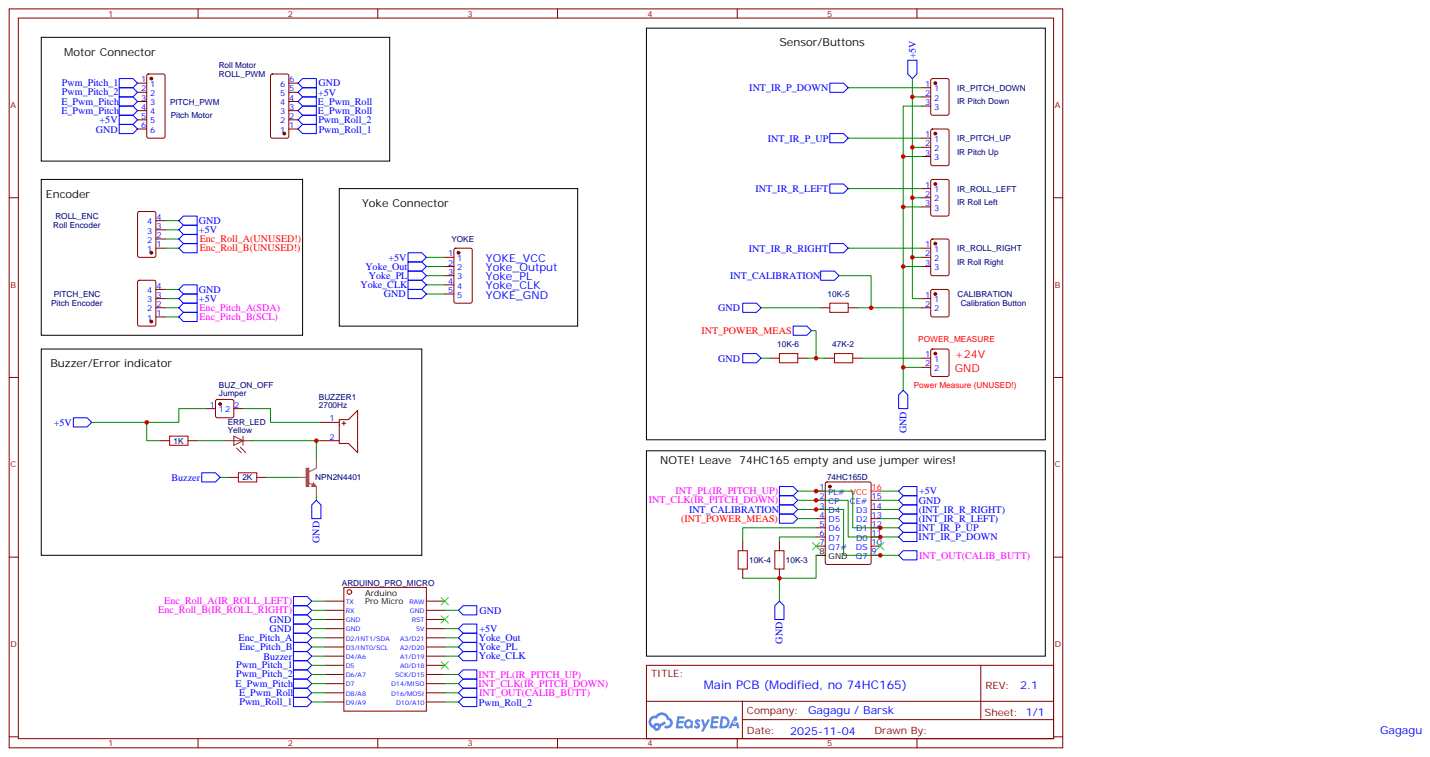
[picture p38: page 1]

NOTE! Leave 74HC165 empty and use jumper wires!

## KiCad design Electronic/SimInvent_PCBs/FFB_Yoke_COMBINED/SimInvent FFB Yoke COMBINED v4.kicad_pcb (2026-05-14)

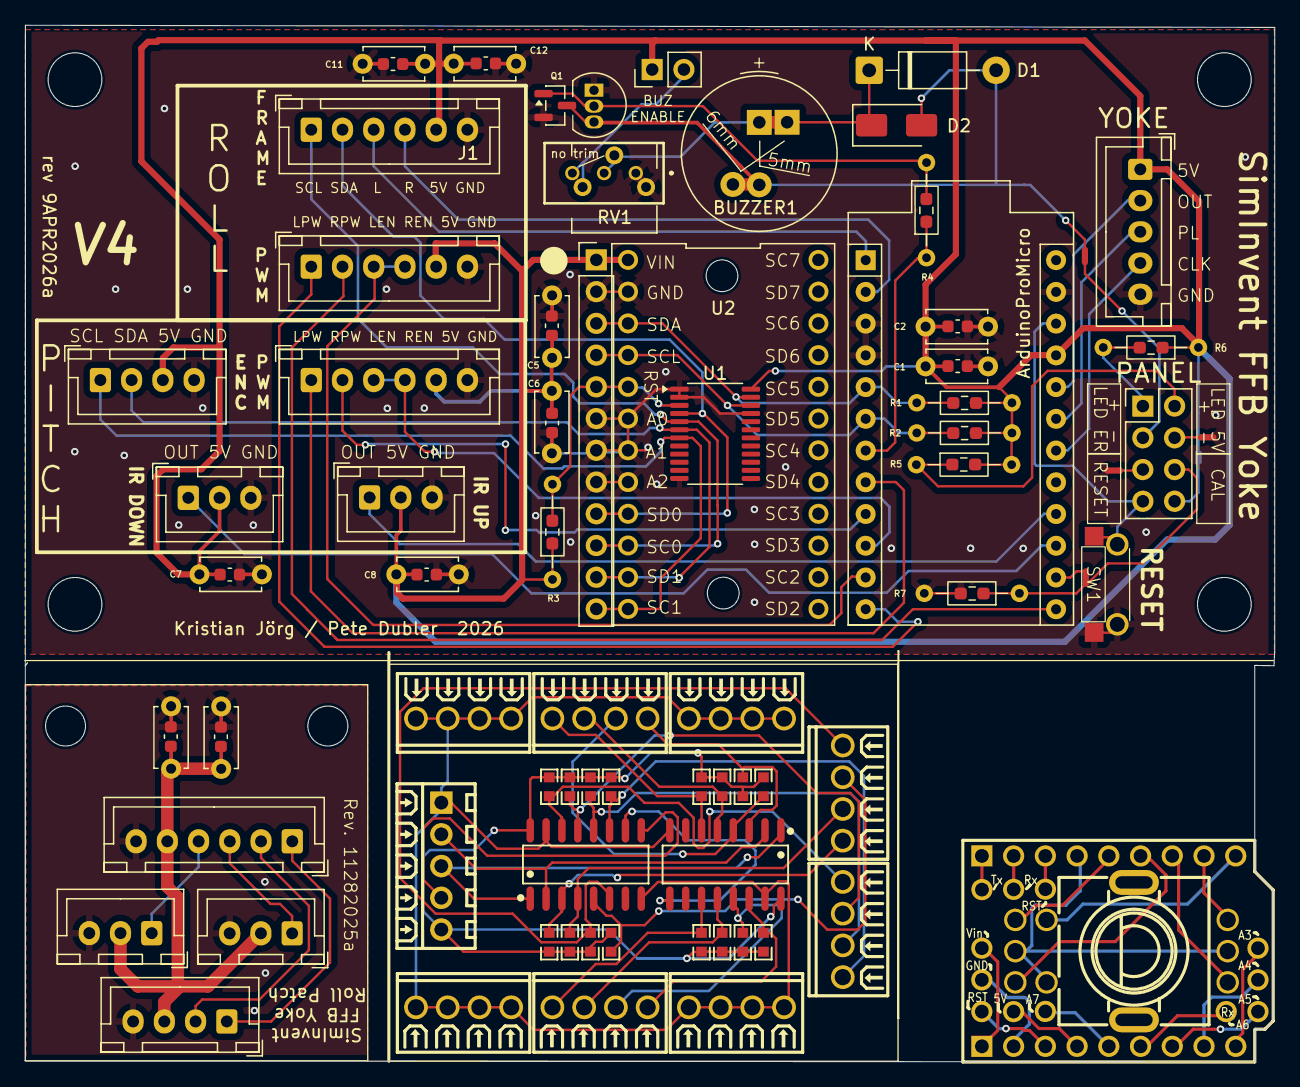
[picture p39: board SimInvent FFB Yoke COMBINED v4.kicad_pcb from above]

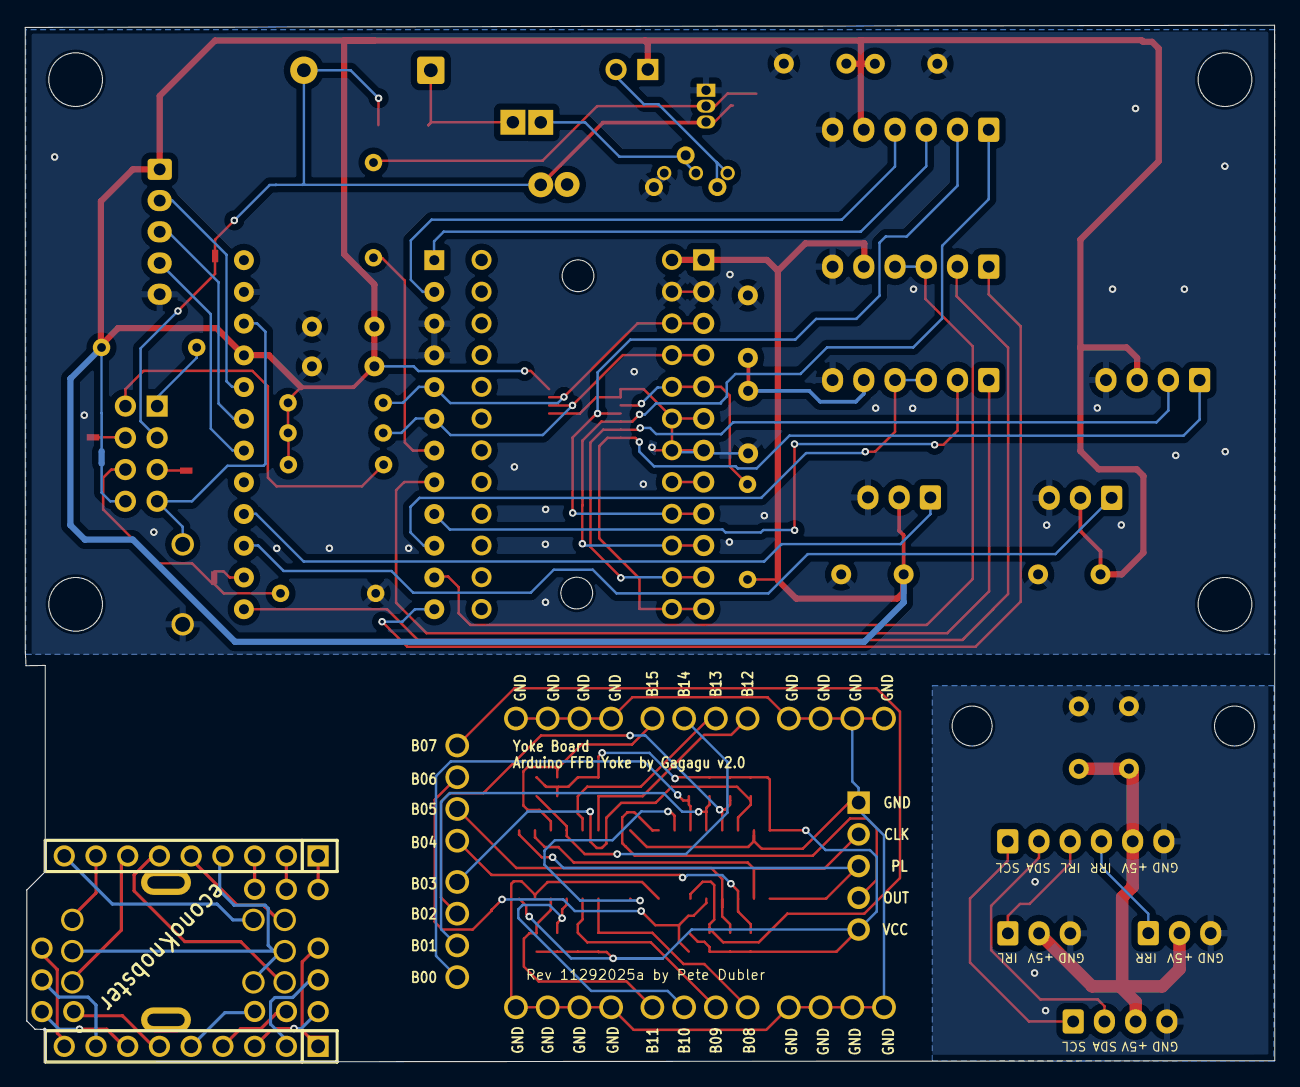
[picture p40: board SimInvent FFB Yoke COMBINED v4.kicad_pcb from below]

Board: 2 copper layers, 100.0 x 83.0 mm, 95 parts (2 on the bottom side), 80 nets.

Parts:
ARDUINO_PRO_MICRO1: ArduinoProMicro; Sparkfun_Pro_Micro
BUZZER1: 2700Hz; Buzzer_TDK_PS1240P02BT_D12.2mm_H6.5mm
C1, C2#2, C6, C12: 10uF; DUAL_CAP_2.5mm_0603
C1#2, C2, C5, C7, C8, C11: 0.1uF; DUAL_CAP_2.5mm_0603
D1: SM4001; D_DO-41_SOD81_P10.16mm_Horizontal
D2: 1N4001; D_SMA
H1, H2, H3, H4#2: MountingHole; MountingHole_4.3mm_M4_DIN965
H1#2, H2#2: MountingHole; MountingHole_3.2mm_M3_DIN965
H1#3, H2#3: HDR-TH_9P-P2.54-V-F-1
H3#2, H4, H5, H6, H7, H8, H9, H10, H11, H12, H13, H14: HDR-TH_1P-P2.54-V-M
IC1, IC2: SOIC-16_L9.9-W3.9-P1.27-LS6.0-BL
J1: Frame Cable; JST_XH_B6B-XH-A_1x06_P2.50mm_Vertical
J1#2: MAIN_BOARD; JST_XH_B6B-XH-A_1x06_P2.50mm_Vertical
J2: Roll Motor; JST_XH_B6B-XH-A_1x06_P2.50mm_Vertical
J2#2: ROLL_ENCODER; JST_XH_B4B-XH-A_1x04_P2.50mm_Vertical
J3: ROLL_LEFT; JST_XH_B3B-XH-A_1x03_P2.50mm_Vertical
J3#2: Pitch Motor; JST_XH_B6B-XH-A_1x06_P2.50mm_Vertical
J4: ROLL_RIGHT; JST_XH_B3B-XH-A_1x03_P2.50mm_Vertical
J4#2: Pitch Encoder; JST_XH_B4B-XH-A_1x04_P2.50mm_Vertical
J5: IR Pitch Down; JST_XH_B3B-XH-A_1x03_P2.50mm_Vertical
J6: IR Pitch Up; JST_XH_B3B-XH-A_1x03_P2.50mm_Vertical
J7: Jumper - Buzzer Active; PinHeader_1x02_P2.54mm_Vertical
J8: Yoke; JST_XH_B5B-XH-A_1x05_P2.50mm_Vertical
J9: Conn_02x04_Counter_Clockwise; PinHeader_2x04_P2.54mm_Vertical
J10: Conn_01x12; PinHeader_1x12_P2.54mm_Vertical
NT1, NT3, NT4, NT6, NT7: NetTie_2; NetTie-2_SMD_Pad0.5mm
Q1: 2N4401; TO-92L_Inline
Q2: MMT4401 alternative; SOT-23
R1, R2#2, R3, R7#2: 10K0; DUAL_RESISTOR_7.62mm_0605
R1#2, R2, R3#2, R4#2, R5, R6#2, R7, R8, R9, R10, R11, R12, R13, R14, R15, R16: R0603
R4: 2K0; DUAL_RESISTOR_7.62mm_0605
R5#2, R6: 220; DUAL_RESISTOR_7.62mm_0605
RV1: 500ohm or 1K; Potentiometer_Vishay_T73YP_Vertical
RV2: 3296W; 3296W1503LF
SW1: PTS636SM43LFS 6X3.5MM; DUAL_TACTILE_SWITCH
SW1#2: SW-TH_EC11EBB24C03
U1: CONN-TH_5P-P2.54_MX128-2.54-05P-GN01-CU-Y-A
U1#2: TCA9548APWR; TSSOP-24_4.4x7.8mm_P0.65mm
U2, U3, U4, U5, U6, U7, U8, U9: CONN-TH_4P-P2.54_MX128-2.54-GN01-04P-CU-Y-A
U2#2: TCA9548A Module

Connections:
5V_POWER_LED+: J9.2, R5#2.1
5V_POWER_LED-: J9.4, NT1.2
$1N177: H1#3.4, SW1#2.2, SW1#2.5, SW1#2.8
$1N178: H1#3.5, SW1#2.3
$1N179: H1#3.6, SW1#2.1
$1N180: H1#3.7, SW1#2.6
$1N181: H1#3.8, SW1#2.4
$1N182: H1#3.9, SW1#2.9
$1N1235: H1#3.1, H14.1
$1N1240: H1#3.3, H12.1
$1N1261: H1#3.2, H13.1
$1N1270: H2#3.1, H3#2.1
$1N1276: H2#3.2, H4.1
$1N1286: H2#3.3, H5.1
$1N1295: H2#3.4, H6.1
$1N1304: H2#3.5, H7.1
$1N1314: H2#3.6, H8.1
$1N1321: H2#3.7, H9.1
$1N1328: H2#3.8, H10.1
$1N1335: H2#3.9, H11.1
+5V: ARDUINO_PRO_MICRO1.21 (5V), C1#2.1, C2#2.1, C5.1, C6.1, C7.2, C8.2, C11.1, C12.1, J1.5, J2.5, J3#2.5, J4#2.3, J5.2, J6.2, J7.1, J8.1, J10.1, NT4.2, R1.1, R2#2.1, R3.1, R5#2.2, R6.1, U1#2.24 (VCC), U2#2.1 (VCC)
/+5V: C1.1, C2.1, J1#2.5, J2#2.3, J3.2, J4.2
/Buzzer-: BUZZER1.2, D1.2 (A), D2.2 (A), NT7.2, Q1.3 (C), Q2.3 (C)
/GND: C1.2, C2.2, J1#2.6, J2#2.4, J3.3, J4.3
/IR_L: J1#2.3, J3.1
/IR_R: J1#2.4, J4.1
/SCL: J1#2.1, J2#2.1
/SDA: J1#2.2, J2#2.2
BUZZER: ARDUINO_PRO_MICRO1.7 (D4/A6), R4.1
CALIBRATION_BUTTON+: J9.8, NT4.1
CALIBRATION_BUTTON-: J9.6, NT6.1, R7#2.1
ERROR_LED+: J9.1, R6.2
ERROR_LED-: J9.3, NT7.1
E_PWM_PITCH: ARDUINO_PRO_MICRO1.10 (D7), J3#2.3, J3#2.4
E_PWM_ROLL: ARDUINO_PRO_MICRO1.11 (D8/A8), J2.3, J2.4
GNDbrd1: ARDUINO_PRO_MICRO1.3 (GND), ARDUINO_PRO_MICRO1.4 (GND), ARDUINO_PRO_MICRO1.23 (GND), C1#2.2, C2#2.2, C5.2, C6.2, C7.1, C8.1, C11.2, C12.2, J1.6, J2.6, J3#2.6, J4#2.4, J5.3, J6.3, J8.5, J10.2, J10.6, J10.7, J10.8, NT1.1, NT3.1, Q1.1 (E), Q2.2 (E), R7#2.2, RV1.1, RV2.1 (CCW), SW1.1, U1#2.1 (A0), U1#2.2 (A1), U1#2.12 (GND), U1#2.21 (A2), U2#2.2 (GND), U2#2.6 (A0), U2#2.7 (A1), U2#2.8 (A2)
I2C_MUX_SCL_INPUT: ARDUINO_PRO_MICRO1.6 (D3/INT0/SCL), J10.4, R2#2.2, U1#2.22 (SCL), U2#2.4 (SCL)
I2C_MUX_SDA_INPUT: ARDUINO_PRO_MICRO1.5 (D2/INT1/SDA), J10.3, R1.2, U1#2.23 (SDA), U2#2.3 (SDA)
IC1_10: IC1.10, IC2.9
INT_CALIBRATION: ARDUINO_PRO_MICRO1.14 (D16/MOSI), NT6.2
INT_IR_P_DOWN: ARDUINO_PRO_MICRO1.15 (D14/MISO), J5.1
INT_IR_P_UP: ARDUINO_PRO_MICRO1.16 (SCK/D15), J6.1
INT_IR_R_LEFT: ARDUINO_PRO_MICRO1.1 (TX), J1.3
INT_IR_R_RIGHT: ARDUINO_PRO_MICRO1.2 (RX), J1.4
LPWM_PITCH: ARDUINO_PRO_MICRO1.8 (D5), J3#2.1
LPWM_ROLL: ARDUINO_PRO_MICRO1.12 (D9/A9), J2.1
unnamed: BUZZER1.1, D1.1 (K), D2.1 (K), RV1.2, RV2.2 (WIPER)
unnamed: J10.5, R3.2, U1#2.3 (~RESET), U2#2.5 (~RESET)
unnamed: Q1.2 (B), Q2.1 (B), R4.2
unnamed: J7.2, RV1.3, RV2.3 (CW)
PITCH_ENC_SCL: J4#2.1, J10.12, U1#2.7 (SC1), U2#2.12 (SC1)
PITCH_ENC_SDA: J4#2.2, J10.11, U1#2.6 (SD1), U2#2.11 (SD1)
RESET_BUTTON: ARDUINO_PRO_MICRO1.22 (RST), J9.7, SW1.2
RESET_GNDbrd1: J9.5, NT3.2
ROLL_ENC_SCL: J1.1, J10.10, U1#2.5 (SC0), U2#2.10 (SC0)
ROLL_ENC_SDA: J1.2, J10.9, U1#2.4 (SD0), U2#2.9 (SD0)
RPWM_PITCH: ARDUINO_PRO_MICRO1.9 (D6/A7), J3#2.2
RPWM_ROLL: ARDUINO_PRO_MICRO1.13 (D10/A10), J2.2
YOKE0: IC1.11, R1#2.2, U6.1
YOKE1: IC1.12, R2.2, U6.2
YOKE2: IC1.13, R3#2.2, U6.3
YOKE3: IC1.14, R4#2.2, U6.4
YOKE4: IC1.3, R5.2, U8.1
YOKE5: IC1.4, R6#2.2, U8.2
YOKE6: IC1.5, R7.2, U8.3
YOKE7: IC1.6, R8.2, U8.4
YOKE8: IC2.11, R16.2, U2.1
YOKE9: IC2.12, R15.2, U2.2
YOKE10: IC2.13, R14.2, U2.3
YOKE11: IC2.14, R13.2, U2.4
YOKE12: IC2.3, R12.2, U4.1
YOKE13: IC2.4, R11.2, U4.2
YOKE14: IC2.5, R10.2, U4.3
YOKE15: IC2.6, R9.2, U4.4
YOKE_CLK: ARDUINO_PRO_MICRO1.18 (A1/D19), IC1.2, IC2.2, J8.4, U1.2
YOKE_GND: IC1.8, IC1.15, IC2.8, IC2.15, U1.1, U3.1, U3.2, U3.3, U3.4, U5.1, U5.2, U5.3, U5.4, U7.1, U7.2, U7.3, U7.4, U9.1, U9.2, U9.3, U9.4
YOKE_OUT: ARDUINO_PRO_MICRO1.20 (A3/D21), J8.2
YOKE_OUTPUT: IC1.9, U1.4
YOKE_PL: ARDUINO_PRO_MICRO1.19 (A2/D20), IC1.1, IC2.1, J8.3, U1.3
YOKE_VCC: IC1.16, IC2.16, R1#2.1, R2.1, R3#2.1, R4#2.1, R5.1, R6#2.1, R7.1, R8.1, R9.1, R10.1, R11.1, R12.1, R13.1, R14.1, R15.1, R16.1, U1.5

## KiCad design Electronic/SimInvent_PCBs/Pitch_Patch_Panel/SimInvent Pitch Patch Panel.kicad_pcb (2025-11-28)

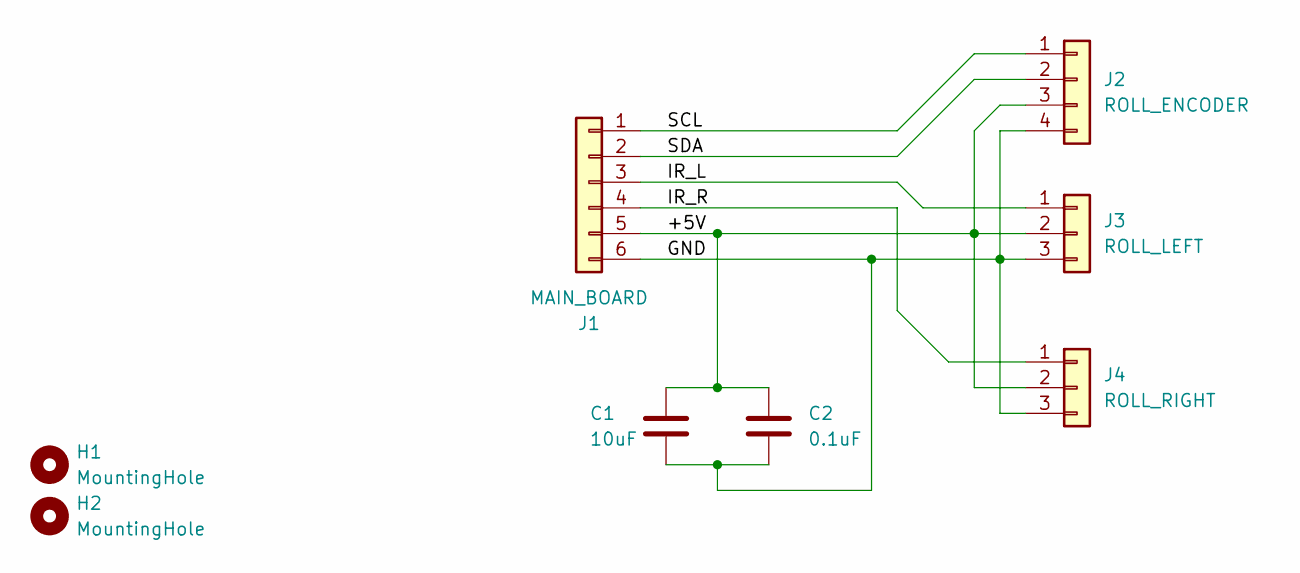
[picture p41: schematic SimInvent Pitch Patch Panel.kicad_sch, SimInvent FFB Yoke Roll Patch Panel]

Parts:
C1: 10uF; DUAL_CAP_2.5mm_0603
C2: 0.1uF; DUAL_CAP_2.5mm_0603
H1, H2: MountingHole; MountingHole_3.2mm_M3_DIN965
J1: MAIN_BOARD; JST_XH_B6B-XH-A_1x06_P2.50mm_Vertical
J2: ROLL_ENCODER; JST_XH_B4B-XH-A_1x04_P2.50mm_Vertical
J3: ROLL_LEFT; JST_XH_B3B-XH-A_1x03_P2.50mm_Vertical
J4: ROLL_RIGHT; JST_XH_B3B-XH-A_1x03_P2.50mm_Vertical

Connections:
/+5V: C1.1, C2.1, J1.5, J2.3, J3.2, J4.2
/GND: C1.2, C2.2, J1.6, J2.4, J3.3, J4.3
/IR_L: J1.3, J3.1
/IR_R: J1.4, J4.1
/SCL: J1.1, J2.1
/SDA: J1.2, J2.2

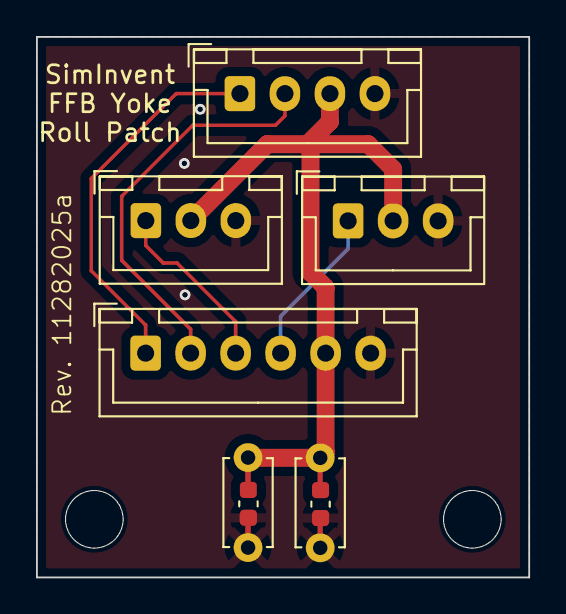
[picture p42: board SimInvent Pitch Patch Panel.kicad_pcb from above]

Board: 2 copper layers, 27.4 x 30.0 mm, 8 parts (0 on the bottom side), 6 nets.

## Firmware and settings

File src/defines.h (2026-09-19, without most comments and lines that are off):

#define DEFINES_H
#define FW_VARIANT "1.0 RC1"
#define FW_EEPROM_VERSION 3  // one byte, max 254, change this if you make changes to the eeprom data structure or want to force reset of eeprom settings
#define NEW_PITCH_CONF_14T true
#if NEW_PITCH_CONF_14T
  #define default_PITCH_PWM_MIN                   43
  #define default_PITCH_TOT_GAIN                  70
  #define default_damperMaxVelocity_PITCH         (24 << VEL_SHIFT)
  #define default_frictionMaxPositionChange_PITCH 200
  #define default_inertiaMaxAcceleration_PITCH    500
  #define MAX_VELOCITY_Y                          (25 << VEL_SHIFT)
  #define CALIBRATION_MOTOR_DELAY_Y               250
  #define CALIBRATION_MAX_PWM_Y                   80
  #define CALIBRATION_MAX_INCREMENT_Y             60
  #define FRIC_FF_STATIC_PITCH                    6
  #define FRIC_FF_VS_PITCH                        200
  #define FRIC_FF_MIN_FORCE_PITCH                 40
#else
  #define default_PITCH_PWM_MIN                   25    // 44 x 0.58
  #define default_PITCH_TOT_GAIN                  40    // 70 x 0.58
  #define default_damperMaxVelocity_PITCH         (11 << VEL_SHIFT)   // 24 x 0.47
  #define default_frictionMaxPositionChange_PITCH 93    // 200 x 0.47
  #define default_inertiaMaxAcceleration_PITCH    233   // 500 x 0.47
  #define MAX_VELOCITY_Y                          (12 << VEL_SHIFT)   // 25 x 0.47
  #define CALIBRATION_MOTOR_DELAY_Y               350   // slower axis, plus gear backlash
  #define CALIBRATION_MAX_PWM_Y                   46    // 80 x 0.58
  #define CALIBRATION_MAX_INCREMENT_Y             28    // 60 x 0.47
  #define FRIC_FF_STATIC_PITCH                    3     // 6 x 0.58, rounded DOWN:
  #define FRIC_FF_VS_PITCH                        94    // 200 x 0.47
  #define FRIC_FF_MIN_FORCE_PITCH                 40    // force units: unchanged
#endif
#define SERIAL_BAUD 115200  // Communication Speed
#define BUZZER_PIN 4
#define IR_ROLL_LEFT 0
#define IR_ROLL_RIGHT 1
#define IR_PITCH_UP 15
#define IR_PITCH_DOWN 14
#define CALIB_BUTTON_PIN 16
#define I2C_SDA 2 // (PIT_A)
#define I2C_SCL 3 // (PIT_B)
#define ENCODER_SLOW_FILTER 3
#define PITCH_EN 7
#define PITCH_U_PWM 5
#define PITCH_D_PWM 6
#define ROLL_EN 8
#define ROLL_R_PWM 10
#define ROLL_L_PWM 9
#define MUX_YOKE_CLK 19
#define MUX_YOKE_PL 20
#define MUX_YOKE_OUT 21
  #define MUX_TOTAL_YOKE 2
#define MEM_ROLL  0
#define MEM_PITCH  1
#define MEM_AXES  2
#define EEPROM_DATA_MAGIC_NUMBER 0b10101010 // Magic number to indicate if valid data is written (used with FIRMWARE_VERSION)
#define EEPROM_DATA_AVAILABLE_INDEX 0     // eeprom address to indicate data available (size 1)
#define EEPROM_FIRMWARE_VERSION_INDEX 1         // version indicator, 1 byte (0-254)
#define EEPROM_ENCODER_X_OFFSET_INDEX  2      // eeprom address of max encoder pos (size 4)
#define EEPROM_ENCODER_X_MAX_INDEX  6      // eeprom address of max encoder pos (size 4)
#define EEPROM_ENCODER_Y_MAX_INDEX  10     // eeprom address of max encoder pos (size 4)
#define EEPROM_MAX_VELOCITY_PCNT_INDEX 14
#define EEPROM_ADJ_PWM_MIN_X_INDEX 15
#define EEPROM_ADJ_PWM_MIN_Y_INDEX 16
#define EEPROM_TOTAL_GAIN_X_INDEX 17
#define EEPROM_DEFAULT_SPRING_FORCE_X_INDEX 18
#define EEPROM_TRAVEL_RANGE_PCNT_X_INDEX 19  // Not used ATM.
#define EEPROM_TOTAL_GAIN_Y_INDEX 20
#define EEPROM_TRAVEL_RANGE_PCNT_Y_INDEX 21
#define EEPROM_DEFAULT_SPRING_FORCE_Y_INDEX 22
#define EEPROM_DATA_INDEX 25              // eeprom start address for data (not used)
#define EEPROM_STACK_WATERMARK_INDEX 30
#define FFB_STACK_TRACE_MS 1000
#define default_gain 100
#define default_friction_gain 100
#define default_spring_gain 50
#define VEL_SHIFT 6
#define PHYSICS_SAMPLE_MS 10
#define default_frictionMaxPositionChange_ROLL 50
#define default_damperMaxVelocity_ROLL ( 5 << VEL_SHIFT)
#define default_inertiaMaxAcceleration_ROLL 140 //120
#define DAMPER_LPF_HZ   12
#define INERTIA_LPF_HZ   8
#define FRICTION_LPF_HZ 12
#define MAX_VELOCITY_X (15 << VEL_SHIFT)
#define VELOCITY_HYSTERESIS (5 << VEL_SHIFT) // max velocity - this value to reenable
#define DEFAULT_VELOCITY_PCNT 60 // default percentage of MAX velocity
#define DEFAULT_SOFT_LOCK_Y_PCNT 80 // default soft lock range in percentage of full range (iMax - iMin) if not calibrated
#define default_PITCH_PWM_MAX 255
#define default_ROLL_TOT_GAIN 100
#define default_ROLL_PWM_MAX 255
#define default_ROLL_PWM_MIN 39
#define PWM_KNEE_FORCE 1200
#define PWM_KNEE_FLOOR_PCT 80
#define ENABLE_FRICTION_FF
#define FRIC_FF_STATIC_ROLL     6
#define FRIC_FF_VS_ROLL         200
#define FRIC_FF_MIN_FORCE_ROLL  40
#define COAST_AT_IDLE
#define COAST_BRAKE_MS 10
#define EXTREMITY_LIMITER_X 0
#define EXTREMITY_LIMITER_Y 20
#define ENDSTOP_HOLD_FORCE 300 // 300
#define default_ROLL_TRAVEL_RANGE_PCNT  100
#define default_PITCH_TRAVEL_RANGE_PCNT DEFAULT_SOFT_LOCK_Y_PCNT  // 80
#define SOFT_LOCK_X 50 // fallback softLock_range when uncalibrated (roll)
#define SOFT_LOCK_FORCE_X 10000
#define SOFT_LOCK_BUFFER_X 40
#define SOFT_LOCK_Y 670 // fallback softLock_range when uncalibrated (pitch)
#define SOFT_LOCK_FORCE_Y 10000
#define SOFT_LOCK_BUFFER_Y 80
#define CALIBRATION_MOTOR_DELAY_X 600
#define CALIBRATION_MAX_PWM_X 55
#define CALIBRATION_MAX_INCREMENT_X 35                // Maximum positional delta change per loop (WHILE_DELAY)
#define CALIBRATION_AXIS_MOVEMENT_TIMEOUT 2000           // Timeout seconds for no movement
#define CALIBRATION_TIMEOUT 20000                        // Timeout seconds for calibration
#define CALIBRATION_SPEED_INCREMENT 2                   // the speed is increased until movement, this is added to speed then movement indicates
#define CALIBRATION_WHILE_DELAY 15                        // waitdelay inside while of movement to give Arduino time. Change will change speed!
#define CALIBRATION_WHILE_DELAY_MOTOR_STOPS 30           // waitdelay when motor stops to give motor time to stop
#define CALIBRATION_DELAY_MOVE_OUT_OF_ENDSTOP 100        // If asix is on endstop on start of calibration it will move out of and wait shortly before continue

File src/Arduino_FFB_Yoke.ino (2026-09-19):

/* 
 Created by A.Eckers aka Gagagu
 http://www.gagagu.de
 https://github.com/gagagu/Arduino_FFB_Yoke
 https://www.youtube.com/@gagagu01


2025 Edited by K. Jörg, @Barsk
https://github.com/barsk/Arduino_FFB_Yoke


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
  By using this code, you acknowledge and agree that you are solely responsible for any 
  consequences that may arise from its use. 

  For DIY projects involving electronic and electromechanical moving parts, caution is essential. 
  Ensure that you take the appropriate safety precautions, particularly when working with electricity. 
  Only work with devices if you understand their functionality and potential risks, and always wear 
  appropriate protective equipment. 
  Make sure you are working in a safe, well-lit environment, and that all components are properly installed and secured to avoid injury or damage.

  Special caution is required when building a force feedback device. Unexpected or sudden movements may occur, 
  which could lead to damage to people or other objects. 
  Ensure that all mechanical parts are securely mounted and that the work area is free of obstacles.
  
  By using this project, you acknowledge and agree that you are solely responsible for any consequences that may arise from its use. 
  The author(s) will not be held liable for any damages, injuries, or issues arising from the use of the project, 
  including but not limited to malfunctioning hardware, electrical damage, personal injury, or damage caused by 
  unintended movements of the force feedback device. The responsibility for proper handling, installation, 
  and use of the devices and components lies with the user.
  
  Use at your own risk.
*/

/*
  This is the MAIN FILE and has to be open in an Directory called "Arduino_FFB_Yoke". Otherwise the building of code will not work.
  This version is usable for Hardware v1.3 with Arduino Micro (original) and Hardware v2.0 with Arduino pro Micro
  See the defines.h for pin and cpu definitions definitions
*/
/*************************
  Includes
**************************/
#include "src/Joystick.h"  // Joystick and FFB Library (many changes made) by https://github.com/jmriego/Fino
#include <AS5600.h>          // Magnetic encoder library
#include <TCA9548.h>         // I2C channel multiplexer, the roll and pitch magnetic encoders goes through here
#include <EEPROM.h>        // https://docs.arduino.cc/learn/built-in-libraries/eeprom

#include "defines.h"
#include "Multiplexer.h"
#include "Axis.h"  // Include the header file
#include "BeepManager.h"
#include "Communication.h"

/*************************
  Variables
// **************************/
unsigned long nextUpdateMillis = 0;    // count millis for next mux update
unsigned long currentMillis;            // millis for the current loop

byte maxVelocityPcnt = 60;             // Percentage of axis max velocity allowed

int16_t forces[MEM_AXES] = { 0, 0 };        // stored forces
Gains gains[FFB_AXIS_COUNT];                // stored gain parameters
EffectParams effects[MEM_AXES];             // stored effect parameters

int16_t adjForceMax[MEM_AXES] = { 0, 0 };  // stored max adjusted force
byte adjPwmMin[MEM_AXES] = { default_ROLL_PWM_MIN, default_PITCH_PWM_MIN };       // stored start pwm (motor power) on force != 0

// TCA9548 I2C multiplexer (actually a switch)
TCA9548 i2c_mux(0x70);

// Magnetic rotary encoders. FastAS5600 skips most register-pointer writes on angle reads
// (see FastAS5600.h); Axis still holds them as AS5600*.
#include "FastAS5600.h"
FastAS5600 rollEncoder;  
FastAS5600 pitchEncoder;
byte ROLL_CHANNEL = 0;
byte PITCH_CHANNEL = 1;

BeepManager beepManager(BUZZER_PIN);  // Instanciate the BeepManager

// variables for calculation
unsigned long lastEffectsUpdate = 0;  // count millis for next effect calculation

#if defined(FFB_SERIAL_TRACE) || defined(FFB_STACK_TRACE)
// ---- stack high-water mark -------------------------------------------------------
// Flash has been budgeted all along; RAM never was. 2125 B of 2560 is static, so only
// ~435 B is shared between the main-loop force chain (loop -> updateEffects -> getForce
// -> forceCalculator -> getEffectForce -> ConditionForceCalculator/ApplyEnvelope, float
// temps throughout) and a USB ISR that nests ~6 frames on top of it (USB_COM_vect ->
// USB_Setup -> PluggableUSB().setup -> DynamicHID_::setup -> SetReport -> CreateNewEffect).
// TelemFFB's startup is exactly when that ISR path is busiest - and it is when the two
// reverted optimisations (Rev 8.13, Rev 8.15) both reset the MCU.
//
// paintStack() fills the gap above .bss with a known byte; stackFreeMin() counts how many
// are still untouched, i.e. the closest the stack has ever come to .bss. A value near 0
// means we are overflowing into .bss and the resets are explained.
extern uint8_t __bss_end;
#define STACK_PAINT_BYTE 0xC5

static void paintStack()
{
  uint8_t *p   = &__bss_end;
  uint8_t *top = (uint8_t *)SP - 64;   // margin: never touch our own frame
  while (p < top) *p++ = STACK_PAINT_BYTE;
}

uint16_t stackFreeMin()
{
  const uint8_t *p = &__bss_end;
  uint16_t n = 0;
  while (n < 2048 && *p == STACK_PAINT_BYTE) { n++; p++; }
  return n;
}

// Previous session's watermark, captured at boot before the slot is re-armed. Reported in
// every P line, so after a crash the FIRST lines of the next session say how close the
// stack came in the session that died - which a live reading can never tell us.
uint16_t stackPrevSession = 0xFFFF;
static uint16_t stackMinSeen = 0xFFFF;

// Called on a timer, not every pass: stackFreeMin() scans up to 434 B (~80 us).
static void recordStackWatermark()
{
  uint16_t now = stackFreeMin();
  if (now < stackMinSeen)
  {
    stackMinSeen = now;
    EEPROM.put(EEPROM_STACK_WATERMARK_INDEX, now);   // put() skips unchanged bytes
  }
}
// ----------------------------------------------------------------------------------

// Main-loop passes since the last 'F'/'P' trace line. x4 = loop Hz. This is the ceiling on
// how fast host effect reports can be accepted: the OUT endpoint is double-banked, so
// each drain point takes at most 2 reports per pass.
volatile uint16_t loopCount = 0;
uint8_t resetFlags = 0;   // MCUSR as latched at boot; see setup()

// An interrupt whose vector is not populated lands on avr-libc's __bad_interrupt, which
// JUMPS TO ADDRESS 0. That restarts the sketch, resets uptime, sets no MCUSR flag and
// leaves the stack untouched - i.e. it produces exactly the signature we are looking at,
// and it is the commonest cause of it on AVR. Defining BADISR_vect replaces that jump
// with this handler, so instead of restarting, the yoke survives and counts the event.
// If the crash disappears and this counter climbs, the fault is named.
volatile uint16_t badIsrCount = 0;
ISR(BADISR_vect) { badIsrCount++; }
#endif

typedef struct {
int16_t lastPos;                        // position from last loop
int16_t lastVel;                        // velocity from last loop (counts/ms << VEL_SHIFT, clamped)
int16_t lastAccel;                      // acceleration from last loop (clamped)
} PhysicsData;

PhysicsData physicsData[MEM_AXES];
int32_t encoderPos[MEM_AXES];
// float angularSpeed[MEM_AXES];

Joystick_ Joystick(            // define Joystick parameters
  JOYSTICK_DEFAULT_REPORT_ID,  
  JOYSTICK_TYPE_JOYSTICK,      // type Joystick
  12, 1,                       // Button Count, Hat Switch Count
  true, true, false);           // X, Y, Z
  // false, false, false,         // Rx, Ry, Rz
  // false, false);               // rudder, throttle

Multiplexer mux(&Joystick);   // class for mutiplexers

Axis axis[MEM_AXES] ={
  Axis(ROLL_L_PWM, ROLL_R_PWM, ROLL_EN, true, &rollEncoder, ROLL_CHANNEL, &i2c_mux, &mux, &beepManager, adjPwmMin[MEM_ROLL]),
  Axis(PITCH_U_PWM, PITCH_D_PWM, PITCH_EN, false, &pitchEncoder, PITCH_CHANNEL, &i2c_mux, &mux, &beepManager, adjPwmMin[MEM_PITCH])
};

Communication comm(&beepManager, gains, adjPwmMin, axis, maxVelocityPcnt);

/********************************
     initial setup
*******************************/
// Explicit prototypes. Arduino's .ino auto-prototype generator is fragile: adding the
// stack-instrumentation block above was enough to make it stop emitting these entirely -
// the profile build still compiled, the release build did not ("not declared in this
// scope" for functions in this very file). Declaring them by hand removes the dependency.
void arduinoSetup();          // Arduino.ino
void enableMotors();          // Arduino.ino
void disableMotors();         // Arduino.ino
void setupJoystick();         // joystick.ino
void setupDefaults();         // joystick.ino
void setRangeJoystick();      // joystick.ino
void updateEffects(bool recalculate);   // joystick.ino
bool isEepromDataValid();     // EEPROM.ino
void writeSettingsToEeprom(); // EEPROM.ino
void readSettingsFromEeprom();// EEPROM.ino
void fullCalibration();       // this file, defined below setup()
void readEEPromCalib();       // this file
void failedCalibration();     // this file
void readEncoderPos();        // this file

void setup() {
#if defined(FFB_SERIAL_TRACE) || defined(FFB_STACK_TRACE)
  // MCUSR latches WHY the last reset happened, and it is the one fact that separates the
  // two remaining candidates: a watchdog fire (the Arduino CDC core arms a 120 ms WDT for
  // the 1200-baud bootloader touch - the only watchdog in the system) from a jump to 0
  // caused by a smashed return address, which sets no flag at all. Read it before the
  // register can be disturbed, then clear it so the NEXT reset reports only itself.
  //   bit0 PORF power-on   bit1 EXTRF external   bit2 BORF brown-out   bit3 WDRF watchdog
  // A Caterina bootloader may consume it first; a constant 0 here means exactly that, and
  // that is worth knowing too.
  resetFlags = MCUSR;
  MCUSR = 0;
#ifdef FFB_STACK_TRACE
  // Stack instrumentation belongs to the S line now; the F line stopped carrying the two
  // figures when force/velocity peaks took their place. Left out of a serial-only build,
  // the paint, the 50 ms scan and the EEPROM slot all drop out with it.
  paintStack();     // must be first: everything below this uses stack
  // Capture what the PREVIOUS session got down to, then re-arm the slot.
  EEPROM.get(EEPROM_STACK_WATERMARK_INDEX, stackPrevSession);
  EEPROM.put(EEPROM_STACK_WATERMARK_INDEX, (uint16_t)0xFFFF);
#endif
#endif
  arduinoSetup();   // setup for Arduino itself (pins)
  Serial.begin(SERIAL_BAUD);  // init serial
  // Cap Stream::readBytes(). Default is 1000 ms: a single stray byte on the CDC port
  // (COM-port enumeration, the VPForce Configurator scanning ports, a leftover serial
  // monitor) makes serialEvent()'s 4-byte read block that long every 100 ms -> the whole
  // FFB loop freezes for ~1 s at a time. A real command's bytes arrive within ~1 ms.
  Serial.setTimeout(15);
  Wire.begin(); // I2C Wire communication
  Wire.setClock(400000); // 400 kHz fast-mode: AS5600 + TCA9548 both support it.
                         // Two muxed encoder reads dominate loop(); at 100 kHz they
                         // capped the force/torque update near ~1 kHz. Revert to
                         // 100000 if long encoder wiring / weak pull-ups misbehave.

  i2c_mux.begin();
  i2c_mux.selectChannel(ROLL_CHANNEL);
  rollEncoder.begin(); 
  rollEncoder.setDirection(AS5600_CLOCK_WISE);
  // CONF is volatile: the filter is re-applied on every boot.  reloadPointer() is what
  // FastAS5600.h asks for after any non-ANGLE register access.  See ENCODER_SLOW_FILTER.
  rollEncoder.setSlowFilter(ENCODER_SLOW_FILTER);
  rollEncoder.reloadPointer();  

  i2c_mux.selectChannel(PITCH_CHANNEL);
  pitchEncoder.begin(); 
  pitchEncoder.setDirection(AS5600_CLOCK_WISE);
  pitchEncoder.setSlowFilter(ENCODER_SLOW_FILTER);
  pitchEncoder.reloadPointer();  

  // if serial debug, no motors enabled
#ifndef SERIAL_DEBUG
  if (digitalReadFast(CALIB_BUTTON_PIN) ||  !isEepromDataValid()) {
    fullCalibration();
  } else {
    readEEPromCalib();
  }

  setupJoystick();  // Joystick and settings

  Joystick.begin(false);
  axis[MEM_ROLL].setMAxVelocityFromPcnt(maxVelocityPcnt);
  axis[MEM_PITCH].setMAxVelocityFromPcnt(maxVelocityPcnt);
#endif
}  //setup

/***************************
      main loop
****************************/
void loop() {
  // if serial debug mode than only display pins, mux and counters
#ifdef SERIAL_DEBUG

  readEncoderPos();

  Serial.print(F("IR_L:"));
  Serial.print(!digitalReadFast(IR_ROLL_LEFT));
  Serial.print(F(", IR_R:"));
  Serial.print(!digitalReadFast(IR_ROLL_RIGHT));
  Serial.print(F(", IR_DN:"));
  Serial.print(!digitalRead(IR_PITCH_DOWN));
  Serial.print(F(", IR_UP:"));
  Serial.print(!digitalRead(IR_PITCH_UP));

  Serial.print(F(", X-axis:"));
  Serial.print(encoderPos[MEM_ROLL]); //Serial.print(F(":")); Serial.print(axis[MEM_ROLL].config.iMin);
  Serial.print(F(", Y-axis:"));
  Serial.print(encoderPos[MEM_PITCH]); //Serial.print(F(":")); Serial.print(axis[MEM_PITCH].config.iMin + axis[MEM_PITCH].config.softLock_range);

  mux.updateJoystickButtons();              // get Joystick buttons

  Serial.println();
  delay(250);
#else
  currentMillis = millis();

  if (currentMillis >= nextUpdateMillis) {
    comm.serialEvent();

    // Calibrate?
    if (digitalReadFast(CALIB_BUTTON_PIN)) {
      fullCalibration();
    }
    nextUpdateMillis = currentMillis + 100;
  }
  // Drain the USB OUT endpoint at several points in the pass, not just once inside
  // updateEffects(). The endpoint is double-banked (EP_DOUBLE_64), so ONE drain point
  // can accept at most 2 reports per loop pass - the host refills the banks on 1 ms USB
  // frame boundaries but nothing looks at them until the next pass. That made effect
  // delivery scale with the LOOP RATE (measured ~200 reports/s), so once TelemFFB wanted
  // more than that the surplus queued host-side and the backlog grew for as long as the
  // demand lasted: latency that builds with time in flight and with effect count, and a
  // stop-on-pause that lands seconds late. The I2C encoder/button reads below are the
  // slow part of the pass, so draining around them is where it pays.
  Joystick.getUSBPID();                     // drain OUT endpoint
  mux.updateJoystickButtons();              // get Joystick buttons
  Joystick.getUSBPID();                     // drain again - updateJoystickButtons is slow (I2C mux)
  readEncoderPos();
  Joystick.sendState(); // send joystick values to system
  updateEffects(true);                      // update/calculate new effect paraeters (drains again)

  for (byte i = MEM_ROLL; i <= MEM_PITCH; i++) {
    axis[i].applyForce(forces[i], encoderPos[i], physicsData[i].lastVel);
  }
#if defined(FFB_SERIAL_TRACE) || defined(FFB_STACK_TRACE)
  loopCount++;
#endif
#ifdef FFB_STACK_TRACE
  { // ~50 ms: fine enough to catch a dive shortly before a crash, cheap enough to ignore
    static unsigned long swLast = 0;
    if (currentMillis - swLast >= 50) { swLast = currentMillis; recordStackWatermark(); }
  }   // reported by the ~1 Hz S line below
#endif
#ifdef FFB_STACK_TRACE
  { // The S line: the same two stack figures the F line carries, but emitted from loop()
    // instead of from inside getEffectForce(). The F line only appears while a host is
    // actually driving effects - which is exactly not the case in the seconds after a
    // reset, when prevMin is the one number worth having. This one repeats regardless,
    // so the terminal can be attached at any time instead of being raced against boot.
    static unsigned long stLast = 0;
    if (currentMillis - stLast >= FFB_STACK_TRACE_MS)
    {
      stLast = currentMillis;
      Serial.write('S');
      Serial.print(stackFreeMin());              Serial.write(',');
      Serial.print(stackPrevSession);            Serial.write(',');
      Serial.print(currentMillis / 1000UL);      // uptime s: a reset shows as this dropping
      Serial.write(',');
      Serial.print(resetFlags);                  // why the LAST reset happened - see setup()
      Serial.write(',');
      Serial.print(badIsrCount);                 // unhandled interrupt vectors caught, not taken
      Serial.write(',');
      { extern volatile uint16_t shortReportCount;   // D5, PIDReportHandler.cpp
        Serial.println(shortReportCount); }      // reports shorter than the struct they feed
    }
  }
#endif
  // Serial.println(millis() - currentMillis);
#endif
} // loop

void readEncoderPos() {
  // Read encoder Positions
    for (byte i = MEM_ROLL; i <= MEM_PITCH; i++) {
      encoderPos[i] = axis[i].getCumulativePos();
      // angularSpeed[i] = axis[i]->readAngularSpeed();
    }
}

/***************************
  Calibration
****************************/
void fullCalibration() {
  enableMotors();             // enable motors
  for (byte i = MEM_ROLL; i <= MEM_PITCH; i++) {
    if (!axis[i].calibrate()) {
      failedCalibration();
      break;
    }
  }

  setRangeJoystick();  // Set Joystick range
}

void readEEPromCalib() {
  enableMotors();
  for (byte i = MEM_ROLL; i <= MEM_PITCH; i++) {
    if (!axis[i].EEPromCalibration()) {
      failedCalibration();
      return;
    }
  }
  setRangeJoystick(); // Set Joystick range
  axis[MEM_PITCH].centerAxis();
}

void failedCalibration() {
  beepManager.beep(250, 300); // Calibration error beep
  disableMotors();
}

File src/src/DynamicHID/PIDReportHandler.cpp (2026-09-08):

#include "PIDReportHandler.h"

#ifdef FFB_SERIAL_TRACE
void ftV(long v)              { Serial.print(v); Serial.write(','); }
void ftTag(char tag, long v)  { Serial.write(tag); ftV(v); }
void ftEnd(long v)            { Serial.println(v); }
#endif

// Constructor: Initializes the PIDReportHandler with default values
PIDReportHandler::PIDReportHandler()
{
    nextEID = 1;  // Next available Effect ID starts at 1
    deviceState = MDEVICESTATE_SPRING;  // Set device state to SPRING mode
    deviceGain.gain = 255;  // B1: full device gain until the host sends Set Device Gain
    pidBlockLoad.ramPoolAvailable = MEMORY_SIZE;  // C1: real starting pool (was left at 0 -> underflow)
}

// Destructor: Frees all effects when the handler is destroyed
PIDReportHandler::~PIDReportHandler() 
{
    FreeAllEffects();  // Free all allocated effects
}

// Gets the next available effect ID and marks it as allocated
uint8_t PIDReportHandler::GetNextFreeEffect(void)
{
    // C2: was `nextEID == MAX_EFFECTS` which made effect ID MAX_EFFECTS unreachable
    // (only MAX_EFFECTS-1 usable). IDs are 1..MAX_EFFECTS, array is [MAX_EFFECTS + 1].
    if (nextEID > MAX_EFFECTS)  // If all effects are allocated, return 0
        return 0;

    uint8_t id = nextEID++;  // Allocate the next effect ID

    // Search for the next free spot in the effect states
    while (nextEID <= MAX_EFFECTS && g_EffectStates[nextEID].state != 0)
        nextEID++;

    // Mark the effect as allocated and update the PID state
    g_EffectStates[id].state = MEFFECTSTATE_ALLOCATED;
    pidState.effectBlockIndex = id;

    return id;  // Return the allocated effect ID
}

// Stops all currently active effects
void PIDReportHandler::StopAllEffects(void)
{
    for (uint8_t id = 1; id <= MAX_EFFECTS; id++)  // effect IDs are 1-based
        StopEffect(id);  // Stop each effect
}

// Starts a specific effect by its ID
void PIDReportHandler::StartEffect(uint8_t id)
{
    if (id == 0 || id > MAX_EFFECTS)  // D1: reject out-of-range indices
        return;

    // Mark the effect as playing, reset elapsed time, and record the start time.
    // Keep the ALLOCATED bit so a subsequent Stop leaves the block allocated (not "free").
    g_EffectStates[id].state = MEFFECTSTATE_ALLOCATED | MEFFECTSTATE_PLAYING;
    g_EffectStates[id].elapsedTime = 0;
    g_EffectStates[id].startTime = millis();
}

// Stops a specific effect by its ID (does NOT free its pool block - see FreeEffect)
void PIDReportHandler::StopEffect(uint8_t id)
{
    if (id == 0 || id > MAX_EFFECTS)  // D1
        return;

    // C1: stopping an effect does not free memory - removed the bogus
    //     `pidBlockLoad.ramPoolAvailable += SIZE_EFFECT;`
    g_EffectStates[id].state &= ~MEFFECTSTATE_PLAYING;
}

// Frees a specific effect by its ID
void PIDReportHandler::FreeEffect(uint8_t id)
{
    if (id == 0 || id > MAX_EFFECTS)  // D1
        return;

    // C1: refund the pool only if this block was actually allocated
    if (g_EffectStates[id].state != MEFFECTSTATE_FREE)
        pidBlockLoad.ramPoolAvailable += SIZE_EFFECT;

    g_EffectStates[id].state = 0;  // Mark the effect as free
    if (id < nextEID)  // Update nextEID if needed
        nextEID = id;
}

// Frees all effects and resets the handler
void PIDReportHandler::FreeAllEffects(void)
{
    nextEID = 1;  // Reset next available effect ID
    memset((void*)&g_EffectStates, 0, sizeof(g_EffectStates));  // Clear all effect states
    pidBlockLoad.ramPoolAvailable = MEMORY_SIZE;  // Reset available memory
}

// Handles effect operation based on the received data (start, stop, loop)
void PIDReportHandler::EffectOperation(USB_FFBReport_EffectOperation_Output_Data_t* data)
{
    if (data->effectBlockIndex == 0 || data->effectBlockIndex > MAX_EFFECTS)  // D1
        return;
#ifdef FFB_SERIAL_TRACE
    ftTag('O', data->operation); ftV(data->effectBlockIndex); ftEnd(data->loopCount);
#endif

    g_EffectStates[data->effectBlockIndex].loopCount = data->loopCount;
    if (data->operation == 1)  // Start effect
    {
        if (data->loopCount == 0xFF)
        {
            g_EffectStates[data->effectBlockIndex].totalDuration = USB_DURATION_INFINITE;
        }
        else if (data->loopCount > 0)
        {
            // Calculate total duration based on loop count
            g_EffectStates[data->effectBlockIndex].totalDuration = (
                g_EffectStates[data->effectBlockIndex].startDelay
                + g_EffectStates[data->effectBlockIndex].duration
            ) * data->loopCount;
        }
        StartEffect(data->effectBlockIndex);  // Start the effect
    }
    else if (data->operation == 2)  // StartSolo: stop all and start a specific effect
    {
        StopAllEffects();
        StartEffect(data->effectBlockIndex);
    }
    else if (data->operation == 3)  // Stop effect
    {
        StopEffect(data->effectBlockIndex);
    }
}

// Handles the BlockFree operation to free one or all effects
void PIDReportHandler::BlockFree(USB_FFBReport_BlockFree_Output_Data_t* data)
{
    uint8_t eid = data->effectBlockIndex;
    if (eid == 0xFF)  // Free all effects
    {
        FreeAllEffects();
    }
    else  // Free a specific effect
    {
        FreeEffect(eid);
    }
}

// Handles device control commands (enable/disable actuators, reset, pause, etc.)
void PIDReportHandler::DeviceControl(USB_FFBReport_DeviceControl_Output_Data_t* data)
{
    uint8_t control = data->control;

    switch (control)
    {
        case 0x01:  // Enable Actuators
            pidState.status |= 2;
            break;
        case 0x02:  // Disable Actuators
            pidState.status &= ~(0x02);
            break;
        case 0x03:  // Stop All Effects
            StopAllEffects();
            deviceState &= ~(MDEVICESTATE_SPRING);
            break;
        case 0x04:  // Reset Device - PID 1.0 s5.13: clear pause, enable actuators, clear effects
            FreeAllEffects();
            deviceState = MDEVICESTATE_SPRING;   // B2: also clears MDEVICESTATE_PAUSED
            pidState.status |= 0x02;             // B2: actuators enabled
            break;
        case 0x05:  // Pause Device
            deviceState |= MDEVICESTATE_PAUSED;
            break;
        case 0x06:  // Continue Device
            deviceState &= ~(MDEVICESTATE_PAUSED);
            break;
        default:  // Handle unknown commands
            break;
    }
#ifdef FFB_SERIAL_TRACE_FULL
    ftTag('D', control); ftEnd(deviceState);
#endif
}

// Sets the device gain based on received data
void PIDReportHandler::DeviceGain(USB_FFBReport_DeviceGain_Output_Data_t* data)
{
    deviceGain.gain = data->gain;  // Update the device gain
}

// Placeholder for setting custom force (not yet implemented)
void PIDReportHandler::SetCustomForce(USB_FFBReport_SetCustomForce_Output_Data_t* data)
{
}

// Placeholder for setting custom force data (not yet implemented)
void PIDReportHandler::SetCustomForceData(USB_FFBReport_SetCustomForceData_Output_Data_t* data)
{
}
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

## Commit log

2025-11-19 Major project update.
    [30T Pulley - Magnet mount.stl, 30T Pulley L.stl, 30T Pulley M.stl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]
2025-11-23 Add README to CAD folder
    [Yoke Controller - Console Front.3mf]
2025-11-24 PD added STLs for standoff mount for new PCB and Motor Driver mount "lite" version, using less plastic.
    [BTS7960 Standoff lite.stl, SimInvent PCB Mount 11242025a.stl]
2025-11-28 SimInvent PCB Folders added to Electronics Folder
    [SimInvent FFB Yoke COMBINED v2.kicad_pcb, SimInvent FFB Yoke COMBINED v2.kicad_sch, SimInvent FFB Yoke.dsn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]
2025-12-12 Updated for new PCBs version
    [SimInvent FFB Yoke COMBINED v2.kicad_pcb, SimInvent FFB Yoke COMBINED v2.kicad_sch, SimInvent FFB Yoke.dsn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]
2025-12-12 Revise README with new features and credits
    Updated README to reflect new features, PCB designs, and credits.
2025-12-19 Updated Frame, Yoke Controller Front and PCB standoff
    [Frame.stl, PCB Standoff (SimInvent).stl, PCB Standoff (old).stl]
2025-12-19 Updated PCB Standoff STL
    [PCB Standoff (SimInvent).stl]
2025-12-20 Updated CAD files after +10 mm length changes
    [AS5600 bracket - pitch.stl, AS5600 bracket - roll.stl, AS5600 bracket.stl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]
2025-12-20 Updated Drill templete after + 10 mm change.
2026-02-18 The pitch and roll initial settings were reversed. The setting of initial EEPROM values was buggy.
    [EEPROM.ino, defines.h, joystick.ino]
2026-02-21 Initial calibration run bugs fixed
    [Arduino.ino, Arduino_FFB_Yoke.ino, Axis.cpp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]
2026-04-02 Added missing Rail mount helper.stl
    [Rail mount helper.stl]
2026-04-09 Add files via upload
    SimInvent FFB Yoke Main Board V 4 finalized 4 April 2026
    Includes BOM file (in GERBERS directory) for JLCPCB assembly with SMD parts.
    Also, combined board gerber files (In-Yoke Board, Patch Board, Main Yoke Board, and econoKnobster boards on one PCB
    [SimInvent FFB Yoke COMBINED v4-Bottom Layer.gbr, SimInvent FFB Yoke COMBINED v4-Bottom Paste Mask Layer.gbr, SimInvent FFB Yoke COMBINED v4-Bottom Silkscreen L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]
2026-05-14 Cleanup and release of v4 PCBs
    [BOM_FFB_Arduino_Yoke_2.0_YokeBoard.csv, PickAndPlace_PCB_FFB_Arduino_Yoke_2.0.csv, SimInvent FFB Yoke COMBINED v2.kicad_pcb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]
2026-05-16 Added yoke controller wiring sketch
2026-05-16 Added missing resitor to the 24V LED indicator in wiring sketch
2026-09-04 firmware: 1.0-RC1 - correctness, latency and force-loop rate
    Everything here came out of driving the yoke from TelemFFB over
    DirectInput, which stacks 10-17 simultaneous effects and reached problems
    that bench testing with one or two never did. Full detail in CHANGELOG.md
    and reference/PID-implementation-review.md.
    Correctness
    - forceCalculator summed every playing effect into an int16, so a full
    MSFS aircraft wrapped past +/-32767 BEFORE the final clamp: an effect
    did nothing alongside others but worked alone, and periodics went
    jerky. Now an int32 accumulator, clamped only at the end.
    - Roll's spring saturated at ~29% of travel - a pitch-only soft-lock
    margin was shrinking roll's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
    [Arduino.ino, Arduino_FFB_Yoke.ino, Axis.cpp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]
2026-09-04 tool: show which firmware is running, and pin the dependencies
    The Yoke Tool now sends the firmware's new <BI> command on connect and on
    every Read, and shows the reply in the status bar:
    Connected COM5, device settings read | firmware sinlut65i-ram ...
    Compatible in both directions. Firmware predating <BI> never answers, so
    the query gets its own 0.3 s timeout and an empty result is not an error -
    an older yoke still connects, just without a build shown. A tool predating
    it never sends <BI>, so nothing changes for it either.
    Also adds tool/requirements.txt, which did not exist: the tool needs
    PyQt6 and pyserial and nothing said so.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
2026-09-05 docs: 1.0-RC1 changelog, README notes, and the descriptor generator
    gen_joydesc.py generates the frozen PROGMEM HID report descriptor that
    Joystick.cpp now carries as a constant, and is checked in so the table can
    be regenerated if the button / hat / axis layout ever changes.
2026-09-08 firmware: default spring gain fix, short-report hardening, stack trace
    The default spring was scaled by total gain twice - once inside its own
    calculation and again in the common gain stage that scales every effect - so
    the Settings Tool slider delivered gain squared: 49% on roll (gain 70) and 20%
    on pitch (gain 45) at a setting of 100%. Host-created springs pick up total
    gain only once and were unaffected, which is why the same spring felt correct
    from a test tool and weak from the tool's own slider. Every other effect type
    applies only its own type gain; the default spring was the sole exception.
    Hardware-confirmed: the spring now matches FFBTestTool at equivalent settings.
    The default spr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
    [Arduino_FFB_Yoke.ino, DynamicHID.cpp, Joystick.cpp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]
2026-09-19 firmware: force loop, sensor path and drive fixes since 1.0-RC1
    Motor drive
    - Brake before coast. Releasing EN with winding current flowing pushed the regen
    spike into the 24 V rail: it tripped a 20 A PSU on every effect stop and reset
    the MCU whenever friction FF was on. COAST_BRAKE_MS (10 ms) shorts the winding
    first, then releases. Hardware-confirmed, and it cured the friction-FF reset
    that earlier stack and layout theories never explained.
    - PWM knee/floor and the Stribeck friction feedforward settled by measurement and
    by feel. The friction FF trio is now per axis: VS is in encoder counts and
    STATIC in PWM counts, so both follow the drivetrain.
    Force loop - about 40% faster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
    [Arduino_FFB_Yoke.ino, Axis.cpp, FastAS5600.h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]
2026-09-20 cad: 14T pitch parts, with the 30T set archived under CAD/old
    The pitch axis now runs 14T pulleys without the planetary gear, so the parts that
    differ are suffixed _14T (pitch motor mount, horizontal belt clamp). The 30T
    versions move to CAD/old/ rather than disappearing - the firmware still supports
    that drivetrain via NEW_PITCH_CONF_14T.
    Also: magnet mounts renamed to a consistent "Magnet mount - axis" pair with a new
    pitch one, a single PCB Standoff replacing the two older variants, and the Alt
    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
    [30T Pulley - Magnet mount.stl, 30T Pulley L.stl, 30T Pulley M.stl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]
2026-09-20 reference: PWM/torque measurements replace the bundled Windows tools
    Three measurement sheets from the bench sweeps behind the low-end defaults -
    pitch and roll, including the repeat runs - plus a README explaining the columns
    and the DirectInput effect-direction convention the yoke follows.
    ForceTest.exe and SimpleHIDWrite.exe are gone: third-party binaries with no
    source in the tree, and FFBTestTool does what they were kept for.
    [pwm-torque-measurement-round2.csv, pwm-torque-measurement-round3-roll.csv, pwm-torque-measurement.csv]
2026-09-20 electronic: V4 main board refresh
    Updated KiCad project files, board notes and BOM, a combined board image, and
    KiCad's backup folder. The stale fp-info-cache is dropped.
    [SimInvent_FFB_Yoke_Main_Board_V4_BOM.xlsx]
2026-09-20 images: new pitch axis, FFBTestTool and effect-direction artwork
    Photos and renders of the 14T pitch axis and its parts, the FFBTestTool screen,
    the fan controller, an SVG of the DirectInput effect-direction compass used in
    the reference notes, and refreshed drill templates and assembly renders.
2026-09-20 docs: 1.0-RC1 release notes and README
    The changelog section now covers the whole release: the force-loop and latency
    work, the low-end motor drive rebuild, the position-sensing and condition-effect
    changes, the pitch drivetrain switch, and a table of the defaults RC1 ships with.
    Figures that had drifted while tuning continued are corrected to the values in
    defines.h.
    README describes the new pitch axis, the tool layout and where SimInvent-TelemFFB
    fits.
